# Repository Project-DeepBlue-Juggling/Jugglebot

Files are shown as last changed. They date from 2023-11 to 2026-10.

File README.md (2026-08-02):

# Jugglebot
For all CAD and code related to Project: DeepBlue Juggling

I'll try to release an updated folder here for every episode in which major changes happen.

For further information about the project as a whole, as well as more detail on specific elements of the project, please head to:
pdj.zulipchat.com

## Hardware bench-rig & analysis tools

A single-ODrive bench rig is set up for isolated single-leg characterisation
(brake resistor, separate PSU, isolated CAN bus). The bench scripts and
analysers are documented in [tools/README.md](tools/README.md):

- **Friction characterisation** — Stribeck four-parameter fit pipeline
  (`cogging_bench_test.py` → `friction_study_analyse.py`)
- **Stiction breakaway** — torque-ramp test with position-only escape detector
  (`breakaway_ramp_test.py` → `breakaway_analyse.py`)
- **Friction feedforward demo** — bench-validation of the FF stack
  (`friction_ff_demo.py`)

Canonical reference: [logbook/2026-04-27-friction-feedforward-bench-validation.md](logbook/2026-04-27-friction-feedforward-bench-validation.md).

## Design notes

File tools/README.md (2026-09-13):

# tools/ — Standalone Hardware Test & Debug Utilities

Scripts in this directory bypass ROS2 and talk directly to hardware via python-can. They are designed for bench testing, bring-up, and diagnostics.

## Generators & drift gates (no hardware, no ROS import)

These are the exception to the sentence above: offline generators whose output
is committed and pinned by a test, so the artifact cannot silently rot. Each
regenerates in place; run it and commit the diff when its source of truth moves.

| Script | Generates | Pinned by |
|---|---|---|
| `gen_choreography_map.py` | `ros_ws/docs/choreography.md` — publisher/subscriber/service/action graph of the Python nodes (`--check` exits 1 on drift) | `tests/ros/test_choreography_map.py` |
| `gen_gui_fk_golden.py` | `tests/ros/gui_fk_golden.json` — Python-IK golden poses replayed through `ros_ws/gui/js/stewart-fk.js` under node | `tests/ros/test_gui_fk_golden.py` |

## Preview Convention (`--preview`)

**Scope**: these rules bind the *operator-facing hardware harnesses* — the
scripts in this directory and in `tests/hardware/` that command the robot and
whose `--preview` previews a motion sequence before it is run. They do **not**
bind the offline analysis probes under `tools/probes/`, which run headless on the
Jetson where a matplotlib window is unusable; there `--preview` conventionally
prints the raw per-sample window instead.

**All test harnesses that accept `--preview` must follow these rules:**

1. **Single window** — `--preview` produces exactly one matplotlib figure containing the full test sequence. Never open a separate window per test.

2. **Unified timeline** — All tests in the suite are stitched end-to-end on a shared time axis. The sequence must be C2-continuous throughout: both *during* and *between* individual tests, all commanded values must be smooth (no step discontinuities in position, velocity, or acceleration).

3. **Return-to-home transitions** — Between tests, generate a proper profiled return-to-home move (not a step command). Highlight these transition segments visually (e.g. light blue `axvspan` shading) so they are clearly distinguishable from test segments. After the final test, return to home and then show the stow segment (highlighted in green).

4. **Test boundary markers** — Mark each test's start/end with vertical dashed lines and annotate with the test name/label.

5. **Scrollbar + zoom** — For sequences longer than ~10 seconds, include a horizontal `matplotlib.widgets.Slider` at the bottom for panning, and bind mouse scroll-wheel to zoom in/out centered on the cursor. See `trajectory_viewer.py:_show_continuous_plots()` for the reference implementation.

6. **5-row plot layout** — Use 5 vertically stacked subplots sharing the x-axis:
   - Row 1: Cartesian Pose (mm / rad) — 6 channels, Cartesian colors
   - Row 2: Cartesian Twist (mm/s / rad/s) — 6 channels, Cartesian colors
   - Row 3: Leg Extensions (mm) — 6 channels, leg colors
   - Row 4: Motor Velocity Feedforward (rev/s) — 6 channels, leg colors
   - Row 5: Torque Feedforward (Nm) — 6 channels, leg colors

   Colors and labels are defined in `trajectory_viewer.py` (`LEG_COLORS`, `CARTESIAN_LABELS`, `CARTESIAN_COLORS`). Import them rather than redefining.

7. **`--dry-run --preview`** — Must work without CAN hardware. Run workspace feasibility checks, then show the preview plot using offline simulation only.

**Reference implementations:**
- `smoother_test.py:preview_all_tests()` — streaming/direct-target preview
- `trajectory_viewer.py:_show_continuous_plots()` — trajectory sequence preview

## Common Patterns

### PlatformTestHarness

`free_platform_test.py` defines `PlatformTestHarness`, the shared base for all multi-leg platform tests. Key usage:

```python
harness = PlatformTestHarness(interface='socketcan', channel='can0')
harness.connect()   # Must call explicitly — __init__ does NOT open the bus
with harness:
    harness.home_all()
    # ... run tests ...
```

Also exports: `LEG_AXES`, `encode_set_input_pos`, `encode_set_controller_mode`, `pose_to_raw_positions`, `error_names`.

### WorkspaceLimits

```python
ws = WorkspaceLimits.from_geometry(geom)  # NOT .from_config()
```

### Shutdown: Always Stow

**Every test harness must end with the platform stowed** (all legs at 0 rev, fully compressed). Never idle axes while the platform is raised — an idled motor provides no holding torque and the platform will drop.

The shutdown sequence is: **return to home → stow (0 rev via TRAP_TRAJ) → idle all axes**.

```python
def stow_platform(harness):
    harness.enter_trap_traj_mode_all(vel_limit=1.5, acc_limit=5.0, dec_limit=5.0)
    for axis_id in LEG_AXES:
        harness.states[axis_id].trajectory_done = False
    for axis_id in LEG_AXES:
        harness.send(encode_set_input_pos(axis_id, 0.0, vel_ff=0, torque_ff=0))
    harness.wait_for_all_trajectories_done(timeout_s=15.0)
```

This applies to:
- Normal completion (after all tests pass/fail)
- Error/exception paths
- Ctrl-C handler (best-effort stow, then idle)

Reference implementations: `tests/hardware/free_platform_test.py` and
`tests/hardware/single_leg_test.py`. (The original references — `smoother_test.py:safe_shutdown()`
and `dynamic_target_test.py:safe_idle_all()` — were pre-MPC harnesses removed with
`tests/archived/` in 67889a6, 2026-04-17; recoverable from git history.)

The `--preview` plot must also show the stow segment at the end of the timeline so the operator sees the full motion the robot will execute.

### Safety

All test harnesses share these safety principles:
- Conservative current limit (50% of rated) set before any motion
- Always stow before idling (see above)
- Mandatory feasibility pre-check before hardware execution
- Interactive confirmation before each test stage
- Heartbeat watchdog on all axes

## Test Harnesses

Every row below names a file that exists today. Paths are given because only one
of these harnesses (`tracking_analyzer.py`) still lives under `tools/` — the rest
are under `tests/hardware/`.

| Script | Phase | Description |
|---|---|---|
| `tests/hardware/single_leg_test.py` | 2 | Single-axis bench tests (torque, e-stop, encoder, force) |
| `tests/hardware/supported_platform_test.py` | 3A | Position control bench tests on a single supported leg |
| `tests/hardware/free_platform_test.py` | 3B-C | Platform-level tests; defines `PlatformTestHarness` |
| `tools/tracking_analyzer.py` | 6 | Rosbag analysis for ball tracking data |
| `tests/hardware/cogging_bench_test.py` | bench-rig | Velocity-mode bench runner with `--sweep`. Produces friction-vs-velocity sweeps for Stribeck fitting. |
| `tests/hardware/breakaway_ramp_test.py` | bench-rig | Torque-mode ramp from rest. Position-only escape detector measures stiction per starting electrical angle. |
| `tests/hardware/torque_step_test.py` | bench-rig | Bidirectional torque-step terminal-velocity test. Reveals controller-fight overhead in velocity-mode measurements. |
| `tests/hardware/friction_ff_demo.py` | bench-rig | Friction-FF effectiveness demo: pos_step / vel_step / sweep modes with Stribeck FF, stiction-boost, and vel_ff toggles. |

**Pre-MPC harnesses (removed 2026-04-17).** Nine harnesses this table used to
list — `trajectory_test.py`, `inertia_test.py`, `hardening_test.py`,
`dynamic_target_test.py`, `juggling_test.py`, `smoother_test.py`,
`trajectory_viewer.py`, `catch_sim_test.py`, `throw_catch_test.py` — were deleted
with `tests/archived/` in commit 67889a6. They exercised the pre-MPC quintic
path-following controller (`control_loop.py`, archived with them) and were
already excluded from pytest. Their test *scenarios* remain valid references for
future MPC hardware tests; recover any of them with
`git show 67889a6^:tests/archived/<name>`.

### Friction characterisation & FF demo (single-leg bench rig)

Four scripts under `tests/hardware/` form a complete friction-characterisation and feedforward-validation pipeline for a single ODrive leg on an isolated CAN bus. Used during the 2026-04-24 to 2026-04-27 bench-validation phase of the motion-onset dead-time investigation.

**Canonical reference:** [logbook/2026-04-27-friction-feedforward-bench-validation.md](../logbook/2026-04-27-friction-feedforward-bench-validation.md) — the bench-validation arc, withdrawn hypotheses, and final fit parameters.

**Pipeline:**

```bash
# 1. Fit Stribeck friction model from a velocity sweep
python tests/hardware/cogging_bench_test.py --sweep 0.075,0.10,0.20,0.30,0.50,1.0,2.0,5.0
python tools/friction_study_analyse.py --glob 'temp/logs/cogging_<ts>*.csv'

# 2. Measure stiction breakaway per rotor angle
python tests/hardware/breakaway_ramp_test.py --direction both --trials 8
python tools/breakaway_analyse.py temp/logs/breakaway_<ts>.csv

# 3. (optional) Confirm against terminal-velocity in TORQUE mode
python tests/hardware/torque_step_test.py

# 4. Validate friction FF + stiction-boost + vel_ff in POSITION mode
python tests/hardware/friction_ff_demo.py
```

All four scripts share safety conventions: 3 rev stroke cap, brake-resistor-aware acceleration cap (250 rev/s²), heartbeat watchdog, IDLE-on-exit. See each script's `--dry-run` output for current parameter limits.

### Friction-FF analysis tools (`tools/*_analyse.py`)

| Script | Inputs | Outputs |
|---|---|---|
| `cogging_map_analyse.py` | one cogging CSV | iq-vs-electrical-angle map, harmonic R² (n=1..12), position-drift slope |
| `friction_study_analyse.py` | multiple cogging CSVs (a sweep) | Stribeck four-parameter fit (τ_c, τ_s, ω_s, b), tracking-quality plots, fwd-vs-rev electrical-map Pearson R |
| `breakaway_analyse.py` | breakaway summary CSV | per-direction breakaway iq stats, angular-dependence harmonic fits, sanity check that breakaway moved more than half a cogging period |

All three accept `--json <path>` to emit a machine-readable result; plots go to `temp/reports/`.

### Tilt calibration grid (contract C-LEVEL-2)

Pose-dependent gravity-level calibration: `level` measures the platform's tilt
against gravity at **one** pose and applies that offset at **every** pose, so
pose-dependent kinematic error is invisible to it by construction. These two
tools measure it over an (x, y) grid and ship it as an interpolatable residual
map.

| Script | Role |
|---|---|
| `tests/hardware/tilt_cal_grid.py` | **Operator-run** capture. Drives the grid via `trajectory/go_to_pose` (never arms, never changes modes, never commands the hand), reads the inclinometer N times per node, writes `config/tilt_calibration.yaml`, reloads it in the running node, verifies the applied version, then re-measures off-node check poses. Runs under **system python3.8 with ROS 2 sourced** — not the venv. |
| `tools/tilt_cal_analyse.py` | Offline. Heat maps + quiver of the residual field, per-node sd table, outlier flagging, and a `--diff` mode for map-invariance (rung C2). Accepts `--json`; reports go to `temp/reports/tilt_cal_<ts>/`. |

**Runbook — read it before running either:** `tests/hardware/session_tilt_calibration.md`
(rungs C0–C3 with numeric PASS/ABORT). Contract: `ros_ws/docs/levelling_frame.md`
§ C-LEVEL-2. Plan: `plans/archived/tilt-calibration-grid.md`.

`tilt_cal_grid.py` takes `--dry-run` (prints the node order and ETA, makes zero
ROS calls) rather than `--preview`: it commands no continuous motion sequence to
plot — it is a series of discrete rest-to-rest moves — so the five-row preview
layout above does not apply. `tilt_cal_analyse.py` is offline analysis and takes
no preview at all, matching `cogging_map_analyse.py`.

⚠ **Several defaults are PROVISIONAL until rung C0 measures them on hardware**
(`--dwell-s`, `--n-reads`, `--read-gap-s`, `--threshold-deg`, the home-node
gate bounds, and the analyser's curvature-flag constants). The SCL3300's noise
floor is unmeasured in this repo; C0 exists to pin it before any test asserts a
threshold.

### catch_sim_test.py

Offline catch simulation that exercises the full pure-Python pipeline: `BallTracker` (Kalman filter + marker matching) → `CatchCoordinator` (catch pose + hand commands) → `TrajectoryManager` (async feasibility + trajectory execution). No ROS2 or hardware required.

**3D visualization** (`--viz`): animated Stewart platform with ball trajectory, KF estimate, landing prediction, hand state indicator, landing error chart, and event timeline. Supports pause/step (Space, arrow keys).

### throw_catch_test.py

Throw-catch cycle: platform throws a ball to itself ((-100,0,170) → (100,0,170) mm), repositions during flight, and catches. Validates the full pipeline including hand throw/catch trajectory timing, platform tilt for throw, and hand catch offset. Reuses the `catch_sim_test.py` animated 3D visualizer.

```bash
python tools/throw_catch_test.py           # text-only results
python tools/throw_catch_test.py --viz     # animated 3D playback
python tools/throw_catch_test.py --viz --apex 500   # lower throw (500mm apex)
```

### catch_sim_test.py

Offline catch simulation that exercises the full pure-Python pipeline: `BallTracker` (Kalman filter + marker matching) → `CatchCoordinator` (catch pose + hand commands) → `TrajectoryManager` (async feasibility + trajectory execution). No ROS2 or hardware required.

**3D visualization** (`--viz`): animated Stewart platform with ball trajectory, KF estimate, landing prediction, hand state, leg extensions, and event timeline.

```bash
python tools/catch_sim_test.py --viz                           # Default throw
python tools/catch_sim_test.py --viz --landing 50 -30          # Specific landing XY
python tools/catch_sim_test.py --viz --landing 0 0 --launch 300 -300 900  # Custom launch
python tools/catch_sim_test.py --landing 0 0 --tof 1.0        # Longer flight
python tools/catch_sim_test.py --viz --noise 10                # High mocap noise
python tools/catch_sim_test.py --sweep                         # Noise sweep (text table)

# Playback controls (--viz):
#   SPACE       play/pause       . / ,     step +1/-1
#   ] / [       step +10/-10     0 / 9     first/last frame
```

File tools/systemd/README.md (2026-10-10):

# User systemd units

Reference copies of the `systemctl --user` units that arm
[`tools/nightly_suite.sh`](../nightly_suite.sh). The **live** copies live at
`~/.config/systemd/user/` — systemd does not read this directory. These are here
so a reimaged or replacement Jetson can be re-armed from the repo, and so a
reviewer can see what is scheduled without shelling into the box.

`nightly` is only an honest test tier while something runs it. If the timer is
lost, every `@pytest.mark.nightly` test silently stops running while
`./run_tests.sh` keeps printing PASS. Treat re-arming as part of any Jetson
rebuild.

## Install / re-arm

```bash
install -Dm644 tools/systemd/jugglebot-nightly.service \
  ~/.config/systemd/user/jugglebot-nightly.service
install -Dm644 tools/systemd/jugglebot-nightly.timer \
  ~/.config/systemd/user/jugglebot-nightly.timer
systemctl --user daemon-reload
systemctl --user enable --now jugglebot-nightly.timer

# Linger must be on, or the user manager (and the timer) stops at logout:
loginctl show-user "$USER" -p Linger      # want Linger=yes
sudo loginctl enable-linger "$USER"       # if it is not
```

## Verify

```bash
systemctl --user list-timers jugglebot-nightly.timer --all
systemctl --user status jugglebot-nightly.service     # last run's exit
tools/nightly_ticker.sh check --who "<session>"        # CLAIMED|LOWERED|STALE|UNRAISED|NEVER — the once-per-day claim; read status only on CLAIMED
cat temp/reports/nightly/status                       # GREEN|RED|DEFERRED <counts> <date>
```

## Keeping these in sync

The install is a **copy**, not a symlink, so the two can drift. `systemctl
--user enable` records the unit by name and a symlinked unit file confuses its
alias handling, which is why this is not symlinked. If you edit a unit, edit it
here, re-run the install block above, and say so in the logbook entry.

Armed 2026-08-01 (`logbook/2026-08-01-nightly-tier-and-mpc-dormancy.md`).

## System unit: `jugglebot-gui.service` (GUI server + replay API)

Unlike the nightly units above, this is a **system** unit
(`/etc/systemd/system/`, `User=jetson`), serving the GUI on :8081 and the
`/api/replay/` rosbag-replay routes. The server itself is stdlib-only and runs
under `/usr/bin/python3`; it lists recordings and serves the `.mcap` bytes over
HTTP Range (the browser decodes them itself). Only the overview worker it spawns
on demand (niced, one at a time) needs the venv, via `--worker-python`; its
results land in `temp/replay_overview/` (gitignored, tens of kB each, `--overview-dir`).
The rosbags root is passed on the `ExecStart` line.

**Migration (Phase 4):** the converter cache is gone. After installing the new
unit, remove the old cache: `rm -rf temp/replay_cache/` (up to 10 GB).

```bash
sudo cp tools/systemd/jugglebot-gui.service /etc/systemd/system/
sudo systemctl daemon-reload
sudo systemctl restart jugglebot-gui
systemctl status jugglebot-gui
```

**Do not restart while someone is using the GUI**: the restart drops every open
page's connection and kills a running overview pass (it is re-run on the next request). Edit the unit here, then re-run the block above;
the install is a copy, so the two can drift.

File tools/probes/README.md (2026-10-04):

# tools/probes/ — Reusable Empirical-Probe Harnesses

Probes fall into two families:

1. **Offline drivers** — scripts that drive the MPC / controller stack in
   a production-faithful way from recorded telemetry, to reproduce
   hardware failures, characterise edge cases, or empirically confirm
   threshold values before they get encoded in tests.
2. **Live observers** — scripts that record system state alongside a live
   session (real robot, real ROS2 stack, real MPC) so a later analysis
   pass can attribute failures to hardware bottlenecks (CPU saturation,
   thermal / DVFS throttling, memory bandwidth, etc).

**These probes are committed to the repo** — distinct from one-off
exploratory probes which still go to `/tmp/probe_*.py`. The split is
codified in `CLAUDE.md`'s "Empirical probe before writing tests" rule.

## Why committed probes exist

Logbook entries and test docstrings reference probes by path. When the
probe lives in `/tmp/`, any reboot wipes the reference. Reusable
harnesses — anything a future investigation is likely to re-run or
adapt — go here so the references stay live.

## Probe conventions

- **Outputs**: probes write CSV / JSON / report files to `temp/probes/`
  (auto-gitignored under the umbrella `temp/` rule). Never write
  run outputs inside `tools/`. Prefer a **timestamped** filename so
  successive runs in one session accumulate rather than clobber each
  other (`fk_convergence_bag_check.py` and `cone_bag_decode.py` both do
  this).
- **Committed reference fixtures** live in `tools/probes/data/`. A probe
  whose gate replays a recording under gitignored `temp/` needs a
  committed cut of it, or the gate is unrunnable on a fresh clone — and
  that cut needs a committed *recipe* (an explicit-output regeneration
  flag), since a fixture nobody can re-baseline is only half a live
  reference. This is the one exception to "no outputs inside `tools/`":
  reference data, not run output, and written only by an explicit flag.
  **Exception, by fixture SHAPE, not by probe**: a fixture that is a
  handful of *measured constants* rather than a data cut is written as an
  importable `.py` under `tests/`, next to the test that reads it —
  `possession_verdict_bag_check.py --emit-fixtures` →
  `tests/ros/possession_fixtures.py`,
  `possession_replay.py --emit-fixture` →
  `tests/ros/toss_verdict_replay_fixtures.py` (the borderline case, and
  it earns the shape: 31 rows of schedule constants plus 157 run-length
  segments, which a reviewer can read, rather than the 21,435 raw
  samples they were cut from). The reason is
  reviewability: a census of a dozen numbers is something a human checks
  and argues with in a diff, and burying it in JSON under `tools/` makes
  a re-baseline look like a blob swap. Data *cuts* (thousands of samples)
  stay in `tools/probes/data/` — e.g.
  `hand_sensor_replay_fixture.json`. Either way the recipe rule is
  unchanged and absolute.
- **Header docstring**: each probe's top-of-file docstring states what
  the probe replays / characterises, the logbook entry that motivated
  it, and the test (if any) whose empirical recipe it underpins.
- **README row**: every committed probe gets a row in § "Available
  probes" below, in the **same commit** that adds the probe. A probe
  nobody can find from this file is a probe nobody re-runs — Phase 0 of
  the 2026-07 refactor programme had to backfill a missing
  `canbridge_reboot_latch_probe.py` row for exactly that reason.
- **Self-contained**: probes set up `sys.path` themselves so they run
  with `python tools/probes/<name>.py ...` from the repo root without
  needing the project venv to be on `PYTHONPATH`.
- **Offline drivers — no hardware**: read recorded telemetry CSVs from
  `temp/logs/` and drive the MPC stack via Python imports, not ROS2 /
  ZeroMQ. Reproducibility against the pinned dependency stack is the
  whole point.
- **Live observers — hardware-allowed, side-effect-free**: may launch
  alongside a real session, but must only *observe* (read `/proc`,
  spawn `tegrastats` / `pidstat`, attach `py-spy`). Never command the
  motors, never send ROS2 messages — that's `tests/hardware/` territory.
  (Carve-out: the GUI verification harness `gui_synthetic_stack.py` and the
  rosbridge CPU probe `rosbridge_cpu_probe.py` publish *synthetic telemetry*
  ROS2 messages, each guarded in code three ways — it refuses to start
  unless the ROS graph is EMPTY, it re-checks the graph at ~1 Hz while
  running and on any foreign node immediately disables all publishers and
  tears itself down (`gui_synthetic_stack.py`) or tears every child down
  outright (`rosbridge_cpu_probe.py`, a batch tool with no state to degrade),
  and it never publishes on a topic any node treats as a
  command. `rosbridge_cpu_probe.py` adds a fourth rail beyond
  `gui_synthetic_stack.py`'s: it runs entirely on a private, non-default
  `ROS_DOMAIN_ID` (87) that it sets for every child it spawns and refuses to
  run on domain 0, so even a race between its graph-empty check and a
  publisher coming up cannot reach a real robot node living on the robot's
  own domain.)

## Available probes

### Offline drivers

| Probe | Purpose | Motivating logbook entry |
|---|---|---|
| `caught_window_bag_probe.py` | The one number behind `skills.executor.CAUGHT_WINDOW_S`: per caught throw, the delay from the ball tracker's own DESCENDING crossing of the 830 mm catch plane (`/balls`, linearly interpolated between the samples either side, candidate tracks filtered to those that actually rose above 880 mm) to the first debounced SEATED sample on `/hand_telemetry` (`ball_held_valid and ball_held`). Both series on their own header stamps, never bag receive time. Reads MCAP through `mcap_ros2` — which decodes from the schema the bag itself carries, so `jugglebot_interfaces` need not be built or sourced, and `rosbag2_py` (absent from the project venv on Foxy) is not needed either. **Report the bags SEPARATELY**: the delay is not one-signed (09-16 ran +43..+282 ms, 09-15 ran −39..−48 ms on all 22 throws), and a statistic pooled across that sign flip is not a physical quantity. ~5 min per 140 MB bag even with the topic filter, so run it in the background. | [2026-09-16-outcome-window-and-computed-catch-deferral](../../logbook/2026-09-16-outcome-window-and-computed-catch-deferral.md) |
| `outcome_landing_replay.py` | **Which landing estimate would the row have recorded?** Replays a bag's `/balls` stream against the memory rows a sitting actually wrote and prints, per throw, the commanded flight, the y as written, the y the CURRENT rule picks (through `executor._consider_landing` itself, not a copy) and whether the physical band admits it. Everything here is in FLIGHT TIME, the quantity that sitting's rows recorded; since 2026-09-18 the learner's outcome is an APEX, so the probe derives its flight band as `sqrt(memory.APEX_RATIO_BAND)` and cannot replay the apex or converged-fit tests (those bags carried neither the landing velocity nor `landing_from_fit`). Built for the 2026-09-16 contamination (rows of 2.2317 / 2.2310 / 1.1554 s for an 0.8569 s command): over both that day's sittings, **43 written rows → 21 refused, 22 admitted at y/u 0.974–1.528** (as written: 0.979–2.985), with the OLD rule reproduced within 12 ms on all 43 — which is what licenses the comparison. Also the instrument that KILLED a candidate rule: "prefer the estimate with the smallest lead to its own crossing" turned three genuine rows into 0.02–0.05 s flights, because the tracker's first post-release estimates predict an immediate crossing. Offline, read-only, needs the project venv + `mcap_ros2` (no ROS2). `--bag` (repeatable), `--learn`, `--date`. | `logbook/2026-09-16-outcome-landing-frozen-at-the-crossing.md` |
| `cone_bag_decode.py` | Decodes the catching cone's `/cone/*` topics straight out of rosbags into a one-command per-session evidence table: `/cone/heartbeat` count, `connected` (n_true/n_total), `time_synced` (n_true/n_total + **was it synced from the FIRST heartbeat?** — the column that settles "did the cone ever sync this session"), `last_catch_seq` range → `taps` (wrap-aware, **reboot-aware** genuine tap count), `/cone/catch_event` count, `/cone/timing_result` count. The `taps` vs `catch_ev` cross-check is load-bearing: `taps` is what the CONE believed happened, `catch_ev` is what the ROS graph actually PUBLISHED — a divergence (` !` in the table) means catch frames were lost in between. Handles both cone firmware eras: the modern `have_any_catch`-gated seq (pre-first-catch `last_catch_seq` is a placeholder) and the legacy May firmware that never set the flag at all (falls back to a plain wrap-aware delta) — `taps == catch_ev` on 17/17 sessions of 2026-07-12 **and** 3/3 legacy `cone_test_*` bags with catches. **Read that 17/17 with its condition attached**: it validates the cone→ROS transport only *because no catch followed either in-session cone reboot* (`18-34-09`, `18-44-56`, both `*`-marked) — a cone MCU reboot resets `last_catch_seq` to 0, and the probe now detects the reset (`have_any_catch` clearing, or an implausible >64-tap single-heartbeat step), restarts the accumulator and marks the row, instead of bridging straight across it and inventing ~250 phantom taps. A genuine count of **zero** is reported as `0`, never as "topic absent" (`-`) — the distinction is drawn from the bag's channel list, because collapsing a real 0 into "absent" silently suppressed the exact frames-lost case the probe exists to detect (cone counted N taps, ROS graph published ZERO `catch_event`s — i.e. the `catch_correlation_node` orphan). `-` now means the bag has no channel for that topic at all. Offline and read-only (opens `.mcap` files only; no node, no socket, no hardware) and needs NO ROS2 — `mcap_ros2` decodes the schemas embedded in the bag, so it runs on a non-ROS2 clone. `--bag` / `--all` (`--match <date>` to narrow; a full ~230-bag sweep takes ~6 min — cost is chunk decompression, not decode) / `--json` (copy to `temp/probes/`). Degrades gracefully on unreadable bags (per-bag `ERROR:` row, sweep continues) and on a missing `--root` (clean error, not a traceback). | `logbook/2026-07-12-gui-cone-catch-correlation-regression.md` (the `timing` column is ground truth for that fix: `/cone/timing_result` is **0** in every session before the rebuild, non-zero after) + `logbook/2026-07-12-cone-sync-udp-link-contention.md` (this probe REFUTED the "cone only syncs right after a colcon build" model — `sync@1st` is `Y` for every session from 15:57 on, straight across the 19:17 rebuild boundary and for three further launches 45 min–3 h later. It then refuted that entry's OWN first attribution of the two dead morning sessions to a co-binding bench harness: the `connected` fractions and the `*` reboot markers show the same dropout-then-reboot signature in sessions with **no bench process running at all**, and a partial-connectivity session (`20-03-36`, 155/593) is a shape an all-or-nothing UDP bind race cannot produce — pointing at cone-side power/wiring intermittency instead) |
| `bench_leg_plant_id.py` | Leg-plant system-ID from recorded `bench_leg_sysid.py --mode strokes` CSVs — offline, no hardware, no new bench runs. Two fits per gain point: (a) the **plant**, by regressing the rigid-body torque balance `2πJ·a = Kt·iq − τ_c·sgn(v) − b·v` on the (a, v, iq) triples → `J_eff`, `τ_c`, `b`; and (b) the **tracking-error budget**, decomposing `err = cmd_u0 − encoder` into `τ_d·v + k_a·a + k_f·sgn(v) + c` → how much of the error is even *attackable by feedback* (the delay term is not: it is gain-independent, and much of it is the metric's own sample-and-hold, since `cmd_u0` is the knot at the START of the segment the firmware is interpolating THROUGH). Prints the cascade table `ω_v = vel_gain/(2πJ)` vs `ω_p = pos_gain` — the ratio that actually decides whether a gain point rings, and which the gain ladder never measured. **Result: `J_eff` = 0.7–1.2 × J_rotor across five independent fits (two highest-R² both at 0.97×), refuting the unsourced "J_eff ~10× rotor" guess the tuning methodology had carried since 2026-04-27 by an order of magnitude; `τ_c` = 0.88–1.22 A, bracketing the 2026-04-27 friction bench's 1.094 A — reproduced from unrelated data.** Caveats in the header docstring — `a` is a numerical derivative so this is ±~20%, good enough to settle a 10× hypothesis and size a feedforward, not a precision inertia measurement; and the bench leg is UNLOADED (no gravity, coupling or hand reaction), so these are a floor, not the loaded-robot budget. `python tools/probes/bench_leg_plant_id.py --all`. | `logbook/2026-07-13-leg-plant-id-and-the-units-bug.md` (the session that ended the leg gain hunt: the "accuracy knee" that motivated the retune was a rev→mm units bug, and the plant this probe identifies shows the cascade was already healthy at production gains) |
| `toss_trace_synth.py` | Synthetic-trace generator + end-to-end verification matrix for the Phase-3 toss-choreography checker (`tests/hardware/toss_trace_recorder.py check`): generates the 2 happy-path traces (waived dry ending `Toss MISSED`; un-waived `REJECTED_NO_BALL`) plus the faithful `ABORTED_NO_RELEASE` variant (dispatch eaten, THROWING reached, no stroke — must banner, SKIP exactly DT-9/DT-12 with DT-5 still evaluated via the THROWING proxy, and exit 0) plus BOTH continuous happy-path traces — `cont_happy` (3-cycle `TossContinuous` session, every cycle CAUGHT: the `ACTION_STAY` teardown) and `cont_dry` (every cycle MISSED: the `SAFE_ABORT` teardown, which is the shape the runbook's MANDATORY CONT-STEP-1 pre-flight actually produces and whose ~10 rev retract lands inside every dwell window CS-3 measures) — plus ONE violation trace per invariant (25 cases, DT-1..14 + RJ-1..4 + CS-1..6 with CS-3 carrying two, one per half — each flips exactly the ordering/property its invariant checks), then `--verify` runs the REAL checker on all 30 and asserts the matrix: happy/variant ⇒ exit 0, every non-SKIP invariant PASS; violation ⇒ exit 1, exactly the targeted invariant FAILs, zero collateral. Includes the empirically-confirmed 2026-07-25 audit inversion (`viol_dt5`: hand cmd-echo changed BEFORE the announcement) which the pre-fix DT-5 silently PASSed — the fixed checker's pre-announcement negative scan hard-FAILs it. Pure stdlib, no hardware, no ROS. `python tools/probes/toss_trace_synth.py --all --verify`, exit 0 = matrix clean. Traces to `temp/probes/toss_trace_synth/`. Re-run after ANY checker change. **2026-07-29**: `viol_dt7` had gone VACUOUS (DT-7 stopped being an "exactly one dynamic_target" count when it was reworked to bound the pre-position STREAM to 30 mm of the nominated point) and the matrix reported MISMATCH at HEAD; the case now injects a target that WANDERS to (95, 0, 170), which is what DT-7 actually guards. **2026-07-29 (Phase F finalize)**: added `cont_dry` and `viol_cs3_hand`. The CS-1..CS-6 matrix had only ever been shown clean on an all-CAUGHT session, while the runbook makes an all-MISSED dry trace the mandatory gate BEFORE any ball flies — an instrument validated on one side only. Adding `cont_dry` immediately surfaced two real CS-3 defects (a hand bound inherited from DT-5's idle window, and a baseline that landed on the retract ramp), both fixed in the checker. | `logbook/2026-07-25-toss-phase3-prep-trace-harness.md` (Phase 3 prep of `plans/archived/single-ball-toss.md`); CS-1..CS-6 added for Phase F (`toss_continuous`) |
| `ilc_speed_band.py` | **DELETED R1 (2026-09-11).** Swept the critical-point-ILC `event_vel_trim` channel against `throw_envelope.evaluate`'s now-deleted `ARM_WINDOW` bound (a reactive-catch-stroke model retired with the mastery latch); not imported by any live test, only cited in prose by `tests/hardware/ilc_fit_lib.py`, `tests/motion/test_ilc_fit.py`, `tests/motion/test_throw_envelope.py` and `tests/ros/test_toss_ilc_node.py` (the critical-point ILC stack itself is superseded, see `plans/archived/critical-point-ilc.md`). | `logbook/2026-08-21-ilc-primary-foldin.md` |
| `cadence_rung_check.py` | **DELETED R1 (2026-09-11).** Drove both FSMs against the legacy per-cycle cadence ladder (`tests/hardware/session_cadence_ladder.md`) and the reactive stroke engine's dispatch budget; the device it verified is retired with the mastery latch. Pinned by `tests/motion/test_cadence_rung_check.py` (also deleted). Its only remaining importer, `tools/probes/toss_loop_census.py`, was itself **DELETED R4 (2026-09-24, `census_fsm_deletion.md` Cluster A)** with `toss_sequencer.py` (the probe read `toss_sequencer.LoopPeriodCensus`'s JSONL output) — both halves of this cross-unit follow-up are now gone. | ILC-primary fold-in Phase K/L — `logbook/2026-08-21-ilc-primary-foldin.md`; cadence-floor + B1 follow-up — `logbook/2026-08-23-cadence-floor-and-inertia.md` |
| `uplot_nan_gap_probe.js` | Node-driven regression probe for the GUI telemetry charts' gap semantics: extracts the SHIPPED `nanGaps` hook verbatim from `ros_ws/gui/js/telemetry-charts.js` and drives the REAL vendored `ros_ws/gui/lib/uPlot.iife.min.js` linear path builder with it, asserting NaN runs render as pen-up gaps (never false bridging lines) — 21 assertions incl. edge runs, all-NaN, single-point NaN, null+NaN merge, dashed-stroke invariance. Pins uPlot-1.6.31-specific behaviour (gap scanner honours strict `null` only; the chart store's Float64Array columns can only carry NaN). Re-run on any uPlot upgrade or `nanGaps`/series-wiring change. `node tools/probes/uplot_nan_gap_probe.js`, exit 0 = pass. | `logbook/2026-07-11-gui-leg-setpoint-echo-poscmd.md` (review HIGH #1: false bridging ramp across stale windows) |
| `fk_convergence_bag_check.py` | Offline FK-convergence verdict for a recorded session: replays every `/robot_state` encoder vector and every `/leg_setpoint_echo` commanded vector from a rosbag through the PRODUCTION `leg_lengths_to_pose` and reports, per topic, how many reconstructions raise under (a) the production default criterion — **the verdict, must be 0** — and (b) the historical absolute-only criterion (`rtol=0, stall_ceiling_mm=0`) — **must be > 0 or the verdict is vacuous**, because it counts how many vectors in that session actually reached the round-off floor; a session whose poses all happen to land under 1e-10 mm reads identically to a genuinely fixed one, so the probe reports that case as a loud `VACUOUS` banner rather than a PASS. Also reports the residual band of the historical failures, the worst residual accepted at the default, and the worst Newton iteration count (50 before the fix, 5 after). Baseline on bag `2026-07-25_15-17-48`: `/robot_state` **514/28953 (1.775 %)** and `/leg_setpoint_echo` **37/10453 (0.354 %)** fail under the historical criterion, 0 under the default; worst accepted residual 9.07e-10 mm; ~92 s per bag (cost is chunk decompression). Strictly offline and read-only — opens `.mcap` files only, no node, no socket, no hardware — and needs NO ROS2 (`mcap_ros2` decodes the schemas embedded in the bag). `--bag` / `--all` (`--match <date>`) / `--json` (→ `temp/probes/`). Exit 0 = PASS, 1 = a reconstruction still fails or a bag was unreadable. | `plans/archived/fk-convergence-tolerance.md` Phases 0–1 — the bare absolute `tol=1e-10` mm was below the reachable round-off floor at part of the workspace, and `trajectory_node`'s seed path turned that into a hard "not streaming until a valid state" refusal (26 consecutive ERRORs in 286 ms on 2026-07-24 09:08:55). The failure is spatially **clustered**, not rare: ±1 encoder dead-band around the burst pose fails **96.8 %** of the time, vs 0 % at `z=50`/`z=110` flat — which is why it bursts. Consuming test: `tests/motion/test_fk_convergence.py` (both its hardware fixtures were extracted with this probe's decode path) |
| `levelling_tilt_bag_check.py` | Offline levelling-frame (C-LEVEL-1) verdict for a recorded session: FK-reconstructs the **commanded** platform pose from every `/leg_setpoint_echo` vector and reports the commanded-tilt **plateau structure** — every run where `rx` sits still, with start time, duration and value in degrees — then, given the session's published offset (`--offset TILT_X TILT_Y`, radians, from the orchestrator's `Gravity offset published:` line), scores three numbers. **`park_rx`/`park_ry` (the longest plateau — where the platform RESTS) is the verdict**, and it is the whole fix in one number: pre-migration the platform parked at plan-frame `rx = 0` while corrected surfaces asked for `-0.7788 deg`, so PASS is `park` within `--tol` (default 0.05 deg) of `(-tilt_x, -tilt_y)`. `settle_rx` is the plateau **furthest from the park in the correction's own direction** (the catch settle — not the last, because post-migration the session ends parked at the corrected neutral; and sign-aware rather than a hard-coded `min()`, which returns the PARK for a positive-rx correction). `peak_above_park` is REPORTED and **never gated**: post-fix it equals the platform's physical peak tilt against gravity and equals `(16/81)*rate*|tdir_x|*lead` = **0.789132 deg per second of catch lead** exactly, so any fixed threshold on it is really a threshold on the lead — the retired `+3.099 deg` ABORT would have fired on a healthy system at any lead >= 3.93 s. The probe prints `implied lead` instead, which on a healthy post-fix session recovers the toss's actual catch lead (the pre-fix bag reads 2.94 s against a true 3.70 s). **Read the header docstring's CAVEAT before scoring**: commanded `rx` is NOT flat across a catch goal and the plan's original "flat to +-0.05 deg across the whole goal" criterion is unreachable — `build_catch` ramps a tilt-through-seat residual along `catch_pose[3:5]`, which with a correction loaded is the correction itself, settling the platform `0.5*0.07*0.15 = 0.005250 rad = 0.3008 deg` OFF gravity-level at ball contact. **Validated on BOTH shapes, which is the acceptance criterion for a verdict instrument.** FLAG side, the real pre-fix bag `2026-07-25_15-17-48` (toss window `--t0 165 --t1 200`, 4.5 s): `park +0.0000 deg` (the defect), `peak +2.3224` above a `0.0000` park, `settle -1.0775` against the closed form `-1.078408` — **err 0.0009 deg**, which is what confirms the through-seat attribution against hardware; 0 FK failures; VERDICT FAIL, correctly, because that bag predates the migration. ACCEPT side, `--self-check` (no bag needed, ~3 s): three sessions synthesised through the PRODUCTION `planner.build_catch` — post-fix must PASS, pre-fix must FAIL, and post-fix contaminated by a 30 s pre-`go_home` ACTIVATE hold must FAIL **with the ambiguity note**, because that hold is commanded at plan-frame `rx ~ 0` and is *correctly* uncorrected (a seed is never corrected), so on a healthy session it can win the longest-plateau vote and read exactly like the pre-fix frame. Hence `--t0` after the first `go_home` is mandatory in CHECK LVL-3. Without the ACCEPT half the instrument would have scored a working fix as FAILED at the bench. Strictly offline and read-only (opens `.mcap` only; no node, no socket, no hardware) and needs NO ROS2. `--bag` / `--root` / `--offset` / `--tol` / `--plateau-tol` / `--plateau-min-s` / `--t0` / `--t1` / `--json` (timestamped, into `temp/probes/`) / `--self-check`. Exit 0 = PASS or STRUCTURE-ONLY (no `--offset`), 1 = park outside tol or unreadable bag. | `plans/parked/levelling-frame-contract.md` Phases 1-2 (and Phase 4, which this is the verdict instrument for) — `trajectory_node` applied the correction on some pose-ingest paths and not others, so the toss's positioning `go_to_pose` parked at plan-frame `rx = 0` while the pre-tilt `catch/dynamic_target` asked for `-0.7788 deg` and `build_catch` planned a min-jerk reach between the two frames, arriving 0.7 s before release. Contract: `ros_ws/docs/levelling_frame.md`. Consuming tests: `tests/ros/test_levelling_frame.py`, `tests/motion/test_levelling.py`, `tests/motion/test_levelling_probe.py` (the two-sided self-check, guarded in CI) |
| `catch_reach_replay.py` | Offline reproduction of a recorded **catch reach** through the production `planner.build_catch`, plus the *install census* that says how many plans spanned it. Three outputs. (1) **Install census** — `move_seq`, `plan_kind`, `last_rejection`, accepted `target_feedback` and `catch/dynamic_target` inside the plan's own window, plus plan-end drift (`t + plan_time_remaining_s`). Five clauses, none sufficient alone. **The load-bearing ones are single-valued `move_seq`, single-valued `plan_kind` (a `HoldPlan` reads `hold`, which is how the emitter backstop / escalation hold / freeze-in-place become visible — they bump nothing else) and zero accepted `target_feedback`.** Plan-end drift is NOT decisive and is not described as such: `_plan_and_install_catch` derives its lead from a fixed `arrival_perf`, so a re-plan to the SAME arrival leaves the plan end untouched — the reference bag's own post-release burst runs `move_seq` 53→64 with 14 accepted feedbacks and drifts **1.02 ms**, LESS than the 1.9 ms across the genuinely zero-install window. There is likewise no status-vs-diagnostics rate advantage: one 5 Hz timer publishes both (1453 messages each over 290.6 s). A rejection only counts if it was RAISED inside the window — `last_rejection` is a lifetime latch that never clears, so gating on "non-empty" would fail every reach after one unrelated session rejection. (2) **The `peak_leg_*` verdict** — it rebuilds the plan and compares the `FeasibilityReport` peaks against what the bag published (`14.2 / 142.4 / 3950`, identical at the published precision — rebuilt `14.2401 / 142.4440 / 3949.7`; the decisive half is the `0.0 / 0.0 / 0` the preceding `go_to_pose` install wrote, which proves the field is WRITTEN). The field is **per-plan, not stale**; it repeats across *these* catch installs because a catch plan's predicted peaks are the fixed-shape 0.15 s through-seat decay's peaks **whenever the reach is small enough for that decay to dominate**. Not a general property: a reload-sized reach runs `82.5→30.1→24.7→15.2→14.0 mm/s` over leads 0.8→8.0 s, and the same bag's two reload catch installs published `23.6` / `23.8` against the toss catches' `14.2` — so predicted peaks MOVING between two catch installs is normal, not evidence of a non-catch plan in between. (3) **The replay** — `build_catch` seeded only from recorded inputs (FK seed pose, `levelling.correct_pose` of the wire target, arrival = `landing − _PRETILT_EARLY_S`), sampled and differenced against FK of `/leg_setpoint_echo`; ONE scalar is fitted (the emit→echo pipeline lag) and the zero-lag residual is reported alongside. All **seven** catch reaches in `2026-07-25_15-17-48` reproduce: 5 self-toss pre-tilts (rx rms 0.005–0.006°, max ≤ 0.039°, lag +10.5 ms) and both reload pre-tilts (rx rms 0.003°, max 0.009°, lag +9.5 ms). The headline closed form is the **amplification** `(16/81)·rate·T / \|tilt\|` = peak *unrequested* excursion ÷ requested displacement — direction-only, so it blows up as the requested tilt → 0: **3.76 for the 0.78° toss pre-tilt, 0.17 for the 11.08° reload pre-tilt**, one code path, 22× apart. That is the whole answer to "why is an 11° reach clean and a 0.78° one not". Verdict tolerance is `max(--tol-deg, --tol-frac × commanded span)` — a purely absolute bound scores the clean 11° reload as NOT-REPRODUCED on a 0.5 % error. **Validated on BOTH shapes, which is the acceptance criterion for a verdict instrument**: the FLAG case (`--toss 2`, the excursion) and the ACCEPT case (`--thrower ball_butler --toss 2`, the clean 11° reload) both read REPRODUCED / exit 0, and `--self-check` case 7 compares all **nine** mirrored rows against their production sources so a change to any of them fails the instrument loudly instead of silently re-scoring old physics. Two of those rows are the 2026-07-26 seat-rate split: `PLANNER_DEFAULT_THROUGH_SEAT_RATE_RADPS` (0.0 — the LIVE default, so raising it off zero breaks the self-check) and `THROUGH_SEAT_RATE_RADPS` (0.07 — a **capture record** of what the reference bag ran at, pinned to itself so nobody "helpfully" syncs it to the new default and makes every pre-2026-07-26 reach score NOT-REPRODUCED). **(4) The C-CATCH-1 counterfactual (added 2026-07-26).** Every scored row also rebuilds the SAME recorded inputs through the post-fix path (`build_fixed`: seat aimed at the gravity-referenced wire tilt, arrival rate left to the planner so `ros_ws/docs/catch_arrival_contract.md`'s bound applies) and prints the delta — unrequested (wrong-side) excursion, settle, segment count, predicted peaks, and whether the `2.5·|d|/T` bound binds. On the reference session the self-toss reach goes `2.3239° → 0.0000°` unrequested excursion with the settle landing dead on the target. **Updated 2026-07-26:** `_CATCH_TILT_THROUGH_RATE_RADPS` now ships at `0.0` (the builder manufactures no motion; an explicit `tilt_through_rate_radps` is still honoured verbatim), so `build_fixed` — which deliberately tracks the shipping planner — now rebuilds the reload reach with **no seat at all**: `3 → 2` segments, arrival rate `0.070000 → 0.000000 rad/s`, settle `+1.8235/−10.9330° → +1.7741/−10.6363°` (exactly the target), predicted `23.8/139.7/3873 → 29.0/37.9/170` mm/s·s²·s³. The earlier "keeps its seat, aim rotated `4.0997°`, settle moved `0.0215°`" reading was the counterfactual at the `0.07` rate and is retained in `ros_ws/docs/catch_arrival_contract.md` § Consequences, because separating the **frame** fix's effect from the **zero-rate** decision's effect is what a bench disagreement needs. REPORTED, never gated — the verdict is about reproducing what the robot DID run, which is why `build_replay` deliberately keeps rebuilding the PRE-fix plan (it passes the arrival rate explicitly, which under C-CATCH-1 means caller-requested and therefore unbounded); a probe that could not express the physics a capture contains could not reproduce it. Self-check cases 9 and 10 make that two-sided and pin the bound factor to `min_s ψ/|φ| = 5/2`. `/gravity_offset` is resolved at the INSTALL, not at end-of-bag, so a mid-session re-`level` cannot score earlier reaches with a later correction. Strictly offline and read-only (opens `.mcap` only; no node, no socket, no hardware) and needs NO ROS2. `--bag` / `--root` / `--toss` / `--thrower` / `--list` / `--offset` (defaults to the bag's `/gravity_offset`) / `--tol-deg` / `--tol-frac` / `--pre` / `--post` / `--json` / `--csv` (both timestamped, into `temp/probes/`) / `--self-check`. Exit 0 = reproduced and the census is self-consistent, 1 = not reproduced, contradictory census, or unreadable bag — **a non-reproduction is a publishable result, not a probe bug**. | `plans/archived/catch-reach-degenerate-overshoot.md` Phase 0 — a `−0.77878°` catch target produced a `+2.32°` commanded excursion in the OPPOSITE direction, settled at `−1.0784°` (1.385× the target), with a leg acc/jerk spike at release − 0.6 s. All three are one plan doing what `build_catch` specifies: the quintic acquiring its specified terminal arrival rate (`φ = −4s³+7s⁴−3s⁵`, extremum `−16/81` at `s = 2/3`), the through-seat overshoot `1 + 0.5·rate·decay/\|tilt\|`, and the 0.15 s through-seat decay segment (10× the reach's acceleration, 113× its jerk). Consuming test: `tests/motion/test_catch_reach_replay_probe.py` (the model-vs-production-planner self-check, guarded in CI). Sibling: `levelling_tilt_bag_check.py`, whose FK reconstruction this reuses |
| `possession_verdict_bag_check.py` | Replays every `/balls` message in a rosbag through the **production** possession source (`jugglebot.ball_possession.TrackerArrivalSource`, constructed exactly as `reload_coordinator_node` constructs it) and prints, per destination-tagged track that reached `CAUGHT`, the estimate, the ARRIVAL error, the REPORT-only plane drop and the verdict the TRACKER SOURCE alone returns. ⚠ **Since owner decision D1 (2026-08-26) that is NOT the coordinator's verdict** — possession is the cup's alone (C-POSSESS-1.D) and the tracker supplies report-only `arrival_err_mm`; for the machine's answer use `possession_replay.py`. This probe scores the tracker's CONTRIBUTION and owns the corpus its split-track behaviour is characterised from. Turns a capture into the two numbers the runbook's `POSS-1` row needs — how many CAUGHT verdicts the gate minted vs how many catches the operator counted by eye — without re-running the sitting. Also **owns the committed test fixtures**: `--emit-fixtures` regenerates `tests/ros/possession_fixtures.py` (all 35 tagged-track CAUGHT estimates of 2026-07-27, 17 self-toss + 18 reload) so the contract's tests are scored on measured ground truth rather than synthetic points. `--self-check` is the two-sided instrument acceptance and needs **no bag**: ACCEPT side (all 17 real catches confirmed), REFUSE side (0/18 corrupt tracks confirmed), the >10x population separation, the bound sitting strictly between them, the retention pin, the 2026-07-23 second-session negative, and **two drift guards mirroring the node's own tolerance and catch point** — 8/8, exit 0 (run 2026-07-28). The reference point defaults to the ACTIVE catch point because a bag does not carry the live goal; `--ref X Y Z` scores a displaced-catch session. Strictly offline and read-only (opens `.mcap` only), `mcap_ros2` imported lazily so the scoring half runs without the bag reader. Outputs a timestamped CSV to `temp/probes/`. | `the anomaly-fixes orchestration prompt (completed, deleted 2026-08-15)` § Follow-on programme, item **B** (cross-referenced from `plans/archived/catch-reach-degenerate-overshoot.md`, whose `CCATCH-2t` row this un-blocks) — the CAUGHT gate was **structurally always False**: it ANDed `\|z − catch_z\| <= 150 mm` onto a quantity that is a dead-reckoned free-fall extrapolation (the tracker declares CAUGHT *because the marker vanished*), so all 17 self-toss catches of 2026-07-27 read `z` error **305–1007 mm** against `xy` error **0.30–3.88 mm** and every one scored MISSED. Contract: `ros_ws/docs/ball_possession_contract.md` (C-POSSESS-1). Consuming test: `tests/ros/test_ball_possession.py`; consuming runbook row: `tests/hardware/session_anomaly_fixes.md` § SECTION POSS |
| `possession_replay.py` | **What would the machine have called each cycle, under the SENSOR-ONLY verdict?** — the acceptance instrument behind owner decision **D1** (2026-08-26). For every self-toss cycle in a bag that reached a release it reconstructs exactly what the live node would have asked the cup: the cycle's SCHEDULED landing (`t_release + flight_time`, the FSM's own `landing_perf`), the cadence clamps `reload_coordinator_node._set_toss_next_cycle_perf` latches (`next_release = landing + dwell`, `next_landing = next_release + flight`, `prev_landing`, including the `intends_another_cycle` rule that decides whether they are latched at all), the real `/hand_telemetry` stream fed sample-by-sample into the shipped `HandBallSensorSource`, and the verdict read at the FSM's OWN deadline `landing + CATCH_CONFIRM_WINDOW_S` through `merge_possession`. **The verdict surface is production; the ask-cadence is modelled** — the label and the edges come from the installed modules, while *when* to ask is restated from the node’s arithmetic (audit N14, 2026-08-26); the reader was `toss_record_miner.read_bag`, deleted 2026-09-13 (R3-f1) — `main()`'s `--bag` path is unreachable until this probe is rebuilt without it; the tested surface below is unaffected. On the reference sitting `2026-08-26_14-25-16` it reproduces the cup census **exactly**: **23 CAUGHT / 4 MISSED** over the 27 cup-adjudicated cycles, every row matching the offline `ball_possession.label_from_sensor` label, against the shipped tracker-primary code's **11 / 16** — 15 false MISSED (twelve of them tracks the tracker never confirmed at ALL, three with a tracker CAUGHT 0.615–0.830 s past the landing) and 3 false CAUGHT over an empty cup, one of which drove a phantom reload. `--emit-fixture` owns `tests/ros/toss_verdict_replay_fixtures.py` in the `possession_fixtures.py` shape (an importable `.py` of measured constants carrying its own regeneration recipe), run-length compressed **21,753 samples → 162 segments**, and the compression is **VERDICT-EQUIVALENT on `(label, blind, catch_dt_s)` at emit time against the source bag** — checked, not claimed: the probe replays both the raw and the expanded stream and refuses to write a fixture whose triples differ. It is NOT lossless (the encoding re-lays sample instants on a nominal `step_s` grid), and the gate is sound for THIS source only, because `HandBallSensorSource` reacts to exactly three things and all three are segment boundaries. **The verdict SURFACE here is production; the ASK-CADENCE is modelled** — the probe reconstructs *when* the node would have asked from the node's own arithmetic, and does not cross the seam that actually failed (`_build_toss_observations` → the FSM). `tests/ros/test_possession_replay.py` carries one node-level test that does. Strictly offline and read-only (opens `.mcap` only). | `logbook/2026-08-26-possession-verdicts-become-sensor-only.md`. Contract: `ros_ws/docs/ball_possession_contract.md` (C-POSSESS-1 § 3.2, clause **D**). Consuming test: `tests/ros/test_possession_replay.py`. Siblings: `hand_sensor_verdict_replay.py` (the same stream with full hindsight, both windows closed — this one answers at the FSM's deadline) and `possession_verdict_bag_check.py` (the tracker's report-only half) |
| `hand_sensor_verdict_replay.py` | Replays a session's **hand ball sensor** through the production possession verdict: reads `/hand_telemetry` + `/throw_announcements` out of a rosbag, feeds every sample into the shipped `jugglebot.ball_possession.HandBallSensorSource` (same `JB_BD_*` windows the node constructs it with) and prints, per announced throw, the sensor's label resolved with **full hindsight** (both windows closed) — `CAUGHT` / `BOUNCE` (arrived then left) / `MISSED` (window closed with no empty→held edge) / `UNKNOWN` (the sensor could not look — which since D1, 2026-08-26, REFUSES rather than falling back to the tracker, and reaches the FSMs as `MISSED_SENSOR_BLIND`). That is the verdict the coordinator would have minted for every label **except `BOUNCE`**: the coordinator answers on the first confirmed tick, where retention is still UNKNOWN and is contract-forbidden from vetoing, so a `BOUNCE` row is a live `CAUGHT` plus the C-POSSESS-1 § 7 reporting residual — which is exactly why it is worth counting offline, being the one count no live log carries — with the **catch-event time** (`arrival edge − predicted landing`), plus the whole-bag sensor ledger (sample count, `ball_held_valid` fraction, transition counts, held-segment durations, sub-second seat-then-leave events). This is the instrument that SIZED the shipped windows: over the three 2026-08-10 retest bags (`16-04-26` / `16-13-48` / `16-30-44`; **203,922 samples, 100 % `ball_held_valid`**, 81 announcements) it labels **35 CAUGHT / 46 MISSED / 0 BOUNCE / 0 UNKNOWN**, with the catch band **+137…+798 ms** (median +399) against a nearest non-catch edge at **+3194 ms** — a ~4x separation, which is what `arrival_lead_s 0.20` / `arrival_window_s 1.50` sit inside. Its transition counts reconcile **exactly** with an independent hand count on all three bags (5/6, 24/23, 38/39 rises/falls). `--merge-tracker {refuse,confirm}` prints the MERGED counterfactual, making the restored-verdict count visible (under the measured pessimistic tracker the pre-2026-08-10 machine mints **zero** catches on these bags; the sensor restores all 35). `--self-check` is the two-sided acceptance and needs **no bag** — 10/10, exit 0 (run 2026-08-10): both ends of the measured catch band ACCEPT, the +3194 ms re-seat REFUSES, the 0.999 s seat-then-leave reads BOUNCE while a hold past the window reads CAUGHT, a **1.55 s hold at the shipped 1.50 s window reads CAUGHT** (the absolute widen guard — the relative case above it follows the constant and can only catch a narrowing), a blind window reads UNKNOWN, a ball that never left raises no edge, and — since D1, 2026-08-26 — the ABSENCE of a tracker fallback is checked in both directions (a confirming tracker cannot rescue a blind cup; a refusing one cannot veto a confirming cup). `--emit-fixture --t0 --t1` owns the committed cut `tools/probes/data/hand_sensor_replay_fixture.json` (16,444 samples of `2026-08-10_16-30-44` over `[140, 305) s`, carrying the band-maximum +798 ms catch, five further catches, two misses and all three seat-then-leave events) and stores its own regeneration recipe inside the file. Strictly offline and read-only (opens `.mcap` only; no node, no socket, no hardware), needs **no ROS 2**, `mcap_ros2` imported lazily so the scoring half runs without a bag. `--json` writes a timestamped report to `temp/probes/`. | `logbook/2026-08-10-sensor-truth-possession.md` — the phase that made the hand sensor the PRIMARY possession source and flipped `toss_require_ball_evidence` to `true`. Contract: `ros_ws/docs/ball_possession_contract.md` (C-POSSESS-1 §§ 3.2, 3.3). Consuming test: `tests/ros/test_hand_sensor_replay.py`. Sibling: `possession_verdict_bag_check.py`, which does the same job for the TRACKER half of the merged verdict |
| `toss_loop_census.py` | **DELETED R4 (2026-09-24, `census_fsm_deletion.md` Cluster A).** Read `toss_sequencer.LoopPeriodCensus`'s JSONL output to answer whether `NODE_LOOP_PERIOD_S = 0.040` was still a bound; `toss_sequencer.py` (the FSM ring) is deleted in the same commit, so the instrument it read no longer exists. Was probe P1 of Phase B0, `plans/archived/toss-pipelined-preamble.md` § 5.1 — see that plan and `logbook/2026-08-26-toss-loop-period-census.md` / `logbook/2026-08-26-phase-b0-measure-first.md` for the historical readings (0.040 s was NOT a bound: 53/73 chained cycles exceeded it, 2026-08-27). | `logbook/2026-08-26-toss-loop-period-census.md`; `logbook/2026-08-26-phase-b0-measure-first.md`; `plans/archived/toss-pipelined-preamble.md` § 5.1, probe P1 |
| `ball_arrival_offset.py` | **Where each thrown ball actually ARRIVED.** For every `/throw_announcements` entry in a rosbag it reads the raw mocap marker stream (`/mocap_data`, unlabelled markers only — the ball carries no rigid body) and reports the ball's `(x, y)` at a horizontal plane (`--plane`, default **1000 mm**) as a least-squares fit of `x(z)`/`y(z)` over the DESCENDING samples in `[plane, plane+band]`, plus `n` and the fitted `z` span. Exists because the 2026-07-27 sitting could not decide its own headline question — three bounce-outs off a stationary 10.8° rim against a measured 26–39 mm BB warm-up drift in arrival `x` — and the A/B that settles it compares outcomes **at matched arrival offsets**, a number the session did not produce (the sitting's own gap list: *"Nothing asks for the ball's measured arrival point... it appears in no log line"*). **Three design points are load-bearing, not stylistic**: the fit is cut at the first sub-plane sample so a bounce-out's post-contact excursion (up to ~70 mm, and in a different direction on different balls) cannot bias a track by an amount that *correlates with the outcome being scored*; it is a fit rather than a nearest-sample read because mocap drops the ball for tens of ms exactly when a track is worst (ball 11 was lost at `z = 1111` and never re-acquired), and `n < 5` is flagged `SPARSE` rather than silently trusted; and a lateral gate removes the room's fixed reflector at `(−537.1, 412.9, 1163.7)`, which sits squarely in the arrival band. `--group NAME=lo-hi` (repeatable) + `--discard N` produce the per-block mean/sd and the matched-arrival check the SEAT-EXP decision rule reads — expressed against the **standard error of the difference of means**, not a flat threshold, because at the measured 9–11 mm sd and `n = 12`/arm a fixed 5 mm gate fires on identically-aimed blocks 17–28 % of the time. It also prints a `PLATEAU (last 8 scored)` mean, which is the statistic `SEAT-EXP-2.2` gates on: the all-scored mean still carries the warm-up excursion and is biased ~10 mm toward passing (`−28.8` vs `−38.9` on the reference capture). **Note `--group` selects on the ANNOUNCEMENT index**, which counts throws that produced no ball (4 of 18 on the reference capture), so the runbook requires one bag per arm rather than counted ranges. **Validated two-sided against the sitting (2026-07-28)**: at `--plane 1050` it reproduces all three published bounce-out entry points — ball 6 `(−6.6, 16.2)` vs `(−7.2, 16.1)`, ball 9 `(−18.5, 3.9)` vs `(−18.8, 3.6)`, ball 11 `(−21.0, 7.6)` vs `(−21.5, 7.4)`, worst error **0.6 mm** — and the population mean `−35.11 mm` vs the published `−34.9`. **Scope that 0.6 mm to what it measures** (bounce-out entry points, at `--plane 1050`) — it is agreement with one published quantity, not this estimator's accuracy: against the sitting's published `x@z1000` series the probe differs by up to **12.7 mm** (attempt 2, `−21.6` published vs `−8.9` here) and by 3.0–3.9 mm on three others, because two defensible estimators on sparse tracks disagree by far more than 0.6 mm. That disagreement is between-estimators and systematic, so it cancels within a sitting (this probe is deterministic and scores both arms) — which is exactly why the decision rule is within-sitting and `SEAT-EXP-6` is expressed against its own standard error rather than a flat millimetre gate. **One number deliberately does NOT reproduce and is recorded rather than buried**: the sitting's *"attempt 3 dropped at −10.7, attempt 4 caught at −14.5, 3.8 mm apart"* reads **−11.507 / −11.525 here, 0.02 mm apart** — the old pair came from an ad-hoc fit whose window is unrecorded and attempt 3 is the capture's sparsest track (3 samples, all above `z = 1100`). The qualitative reading is unchanged and sharper, but it is why **no absolute number from the hand analysis is a gate** and the SEAT-EXP rule is within-sitting with both arms scored by this probe. The floor census (new resting clusters after each attempt) is **REPORT-only** and its measured failure mode is documented in the header: it over-counts a rolling ball and under-counts two balls resting within `--floor-radius` (attempt 3's rested 111 mm from attempt 2's, so it merges and reads 0). Deliberately NOT tuned to make that capture come out right. `--self-check` is the no-bag acceptance: **8 cases**, two-sided (recovers a known crossing to 0.084 mm; proves the post-contact cut holds — as a real MUTATION check, grafting the bounce-out back INSIDE the fit band and requiring the naive fit that kept those samples to move (481 mm here), after a 2026-07-28 review found the original graft sat at `z = 700`, i.e. *below* the plane where the band filter drops it either way, so a probe with the cut deleted scored `8/8 PASS, exit 0`; re-verified both ways — mutant now `FAIL (1 case)` exit 1, unmutated `PASS` exit 0; extrapolates a sparse high-only track; REFUSES a track that never enters the band; sample-sd `n−1`; a one-sample block reports NO sd rather than 0.0, which would make the instrument's own data loss decisive; and **two cases on the sitting's real numbers** — the burn-in trend gate must REFUSE the measured warm-up (`−7.13 mm/throw`) and ACCEPT the measured plateau (`−1.75`), while the criterion the sitting first proposed (*successive change < 10 mm*) is pinned as one that FIRES ON A GOOD PLATEAU (largest successive change there is 15.6 mm), so it cannot be re-adopted from the prose). Strictly offline and read-only, `mcap_ros2` imported lazily, timestamped CSV to `temp/probes/`. | `plans/archived/catch-reach-degenerate-overshoot.md` follow-on phase C — the seat rate became the YAML key `trajectory_op.catch_seat_rate_radps` so the A/B is a config toggle; this probe is what makes "matched arrival offsets" a measurement. Evidence base: `logbook/2026-07-28-anomaly-fixes-validation-sitting.md`. Consuming test: `tests/motion/test_ball_arrival_offset_probe.py`; consuming runbook rows: `tests/hardware/session_anomaly_fixes.md` SECTION SEAT-EXP (`SEAT-EXP-4`, `SEAT-EXP-6`, `SEAT-EXP-7.1`) |
| `hand_decel_authority.py` | Characterises the hand's POST-RELEASE deceleration from a `toss_trace_*.jsonl` and answers the one question that decides the shape of a fix: is the plant **AUTHORITY-limited** (achieved decel saturates ⇒ steepening the commanded ramp changes nothing) or **TRACKING-limited** (achieved follows commanded with a shortfall ⇒ more commanded braking torque buys margin directly)? Per self-toss it emits the commanded decel and `t_dec` re-derived from the SHIPPED firmware header (`Teensy_code_platform/hardware_config.h`, namespace `TeensyTraj` — parsed, not copied), the measured `peak`, `over_x3`, the implied tracking fraction `eta = d_dec/(d_dec + over_x3)`, max \|iq\| over the decel ramp (anchored on the COMMANDED profile, with the count of genuinely fresh `iq` samples in that window) and over the arrest, the residual velocity feedforward standing after the stroke, and the settled `pos_meas - pos_cmd`; per tier it adds the decel-side reflected-inertia LOWER BOUND `(tau_FF + tau_grav)/(2*pi*a_achieved)` and the authority table it implies at `hand_curr_limit_a`. On the 2026-07-27 sitting it measured `eta` = **0.982 / 0.985 / 0.921 / 0.799** at 2.74 / 3.44 / 3.97 / 4.86 m/s — i.e. the achieved deceleration keeps GROWING (911 → 2330 rev/s²) with no ceiling in sight, and the whole-session max \|iq\| is **25.67 A against a 50 A limit** — so the plant is tracking-limited, not current-saturated. But the same table shows the commanded decel at the shipped `FLIGHT_TIME_MAX_S = 1.10 s` is already **83-86 % of the axis's torque-limited ceiling**, which is why steepening was rejected and the feedforward corrected instead. **The caveat is load-bearing and is printed by the tool**: `hand_telemetry` is a ~100 Hz snapshot of a 500 Hz stream and `iq_meas` has a median repeat-run of **4 samples** (mean 7.8, max 918) ⇒ effective refresh ~13-25 Hz, so every current is a LOWER bound and **the gated bench rows must rest on the KINEMATIC columns, not the current ones** — which is why the per-tier inertia bound it prints uses no `iq` measurement at all (binding value **1.0126e-5 kg·m²**; the regression identification 1.050e-5 lives in the contract). It also refuted a hypothesis in passing: the settled `pos_meas - pos_cmd` offset (per tier: **+0.067** at 2.74 m/s, **+0.043…+0.066** at 3.44, **+0.019…+0.041** at 3.97, **−0.004…+0.007** at 4.86 — it SHRINKS with speed) is NOT the residual velocity feedforward, whose median through the same windows is 0.00-0.02 rev/s. **Two defects of one class were found and fixed 2026-08-23, and both were upstream of every number above.** (1) **The window.** `peak` was the max `pos_meas` over the ~400 ms after the commanded stroke end, and `over_x3` / `eta` / the inertia bound all derived from it — but C-HAND-1's gated catch arm dispatches its prelude 37–183 ms into that window and climbs back past `x3`, overshooting by a measured 0.046–0.222 rev, so on any throw whose own coast tops out lower the reported peak is **the arm's move ~200 ms after the throw**. Measured contamination: **10 of the 17 tosses of the 2026-07-27 sitting the C-HAND-2 numbers come from** (both low tiers on every toss — reported `over_x3` +0.074/+0.063 rev against coasts that actually finished −0.051/−0.092 rev, i.e. BELOW `x3`), and **15 of 15** on the first ladder flown unclamped. The identification columns are now bounded at the first post-stroke command (`cst_pk` / `cst_min` / `over_x3` / `under` / `eta` / the bound); **`peak` deliberately keeps the wide window** because the end-stop question wants the largest excursion of ANY cause, and a `*` marks the tosses where the two differ. (2) **The torque.** The per-tier bound multiplied `tor_legacy` — the pre-C-HAND-2 feedforward — long after Platform FW 2 put `throwDecelToTorque` aboard, understating the shipped braking torque by **1.289×** and the bound with it; it now reads the latched wire torque off the capture and PRINTS which generation it found. A third column, `under`, carries the over-brake side, which no maximum over any window can express. **The bound is also no longer asserted unconditionally**: it is a LOWER bound only while the coast finishes above `x3`; a coast that ends below it never caught `pos_cmd`, so `τ_loop` pushed up and the same expression is an UPPER bound — flagged per tier, because the two cases cannot be pooled. Strictly offline and read-only. `--self-check` (two-sided synthetic gate: a PRE-fix capture must score FLAG and a POST-fix one ACCEPT, through the same `analyse()` the bench uses — bench row INST-6; both synthetics now carry the arm prelude, without which the window bug passes its own gate) / `--trace` (one or more) / **`--bag`** (rosbag directories — what the § CHECK HAND-7 recording command actually produces; before this the named authority could not read the capture the ladder makes) / `--robot` / `--curr-limit-a` / `--json` (→ timestamped file under `temp/probes/`). Now exercised by `tests/motion/test_hand_decel_authority_probe.py` (7 cases, mutation-verified) — until then nothing in the suite executed this file at all. | `logbook/2026-07-28-anomaly-fixes-validation-sitting.md` (§ Discussion → *the hand's end-stop margin above 0.78 m*, and the 2026-07-28 amendment: the hand made **light physical contact with its end stop**). Underpins contract **C-HAND-2** (`ros_ws/docs/hand_decel_feedforward.md`) and its tests `tests/sim/test_hand_throw_decel_ff.py` + `tests/firmware/test_hand_throw_decel_xref.py`. Re-run by `tests/hardware/session_anomaly_fixes.md` § CHECK HAND-7 to score the post-flash capture against these pre-fix numbers. |
| `hand_contact_softness.py` | **Is the catch IMPACT measurable on the hand drive channels?** — the Phase-0b probe of `plans/archived/critical-point-ilc.md`. For every catch in a bag it extracts `/hand_telemetry` `vel_meas` / `iq_meas` around the arrival edge and answers, in the order the plan fixes: (1) the **cadence census** — *distinct-value transitions per second*, not samples, because `iq_meas` reaches the bag through the on-change (\|Δiq_setpoint\| > 0.5 A) / 1 Hz-forced DIAGNOSTIC path and is republished at 100 Hz from a cache (`Teensy_code_canbridge/telemetry.cpp:21,24,61` + `teensy_bridge_node.py:2271`), so the publish rate is not the refresh rate; (2) the **transient census** against a stated noise floor AND — the part that actually decides it — two **matched controls**: a same-duration window 0.5–0.8 s earlier in the same cycle (paired, sign-tested) and the same window on a MISSED toss at matched phase (same choreography, no ball); (3) the pre-registered outcome (i)/(ii)/(iii) from an explicit rule, plus a fourth **UNREGISTERED** cell the plan does not enumerate, reported rather than rounded into the nearest box. **Result: the naive comparison is a trap and the probe exists to say so.** Contact-window peak \|Δvel\| on `2026-08-10_16-30-44` is 1.715 rev/s against a *static* floor p99 of 0.195 — an apparent 8.8× (measured 2026-08-12) — but the hand is not still at contact, `vel_meas` tracks `vel_ff_cmd` to ~1 % through the catch stroke (−12.136 vs −12.320, −28.186 vs −27.720, −42.978 vs −43.120 rev/s on three consecutive samples), and at **matched phase CAUGHT vs MISSED separate by 1.03× on \|Δvel\| and 1.45× on the iq impulse** (both under the 1.5× bar; measured 2026-08-12 with the iq impulse referenced to a DISJOINT quiet-held baseline — referencing it to the control window's own median, as the first cut did, scores the control at its own L1 minimum and manufactured a 3.55× within-cycle "separation" out of null data) — i.e. not at all. Two floors are always reported (static / moving) for exactly this reason. Reads the bag through `toss_record_miner.read_bag` + `mine_bag` (the labelling authority; that reader was deleted 2026-09-13, R3-f1 — `--bag`/`analyse_bag` are unreachable until this probe is rebuilt without it, `--self-check` is unaffected) and adds one light second pass for the drive fields, which are not part of `SensorSample`. `--bag` (repeatable) / `--all --match` / `--json` (→ `temp/probes/`) / `--self-check` (**28 synthetic cases, exit 0, run 2026-08-12**, every DETECT twinned with a REFUSE; its command profile is periodic at *exactly* the contact→control offset so the zero-impact case cannot separate on the command alone — the first draft did, and reported "resolvable" on a series containing nothing). Sequential bag processing (8 GB box). Consuming test: none (`tests/ros/test_ilc_measurement_probes.py`, deleted 2026-09-13 R3-f1, was its last one — its target probes were not themselves deleted). | `plans/archived/critical-point-ilc.md` § Phase 0b + § Design constraint 4 (contact softness) + risk 2; the SNR→0 framing (owner, 2026-08-11) is what the matched controls operationalise |
| `hand_sensor_settle.py` | **The messy-catch score** — the Phase-0d probe of `plans/archived/critical-point-ilc.md` (owner metric, 2026-08-12: the hand sensor is highly reliable, so a reading that bounces between BALL and EMPTY after arrival is a messy catch). Order fixed by the plan: (1) the **distinct-sample cadence census** — `ball_held_stamp` advances, not `/hand_telemetry` messages, since the flip count is bounded by the poll and not the 100 Hz republish — which **re-verified the toss-build 2a findings exactly on the reference bag** (poll p5 32 / p50 71 / p95 111 ms vs a configured 20; debounce lag 0/0/0 ms on the catch edge, 232/241/295 ms on the departure edge) **and then refuted them as a standing plant property**: across the eleven bags (ten 2026-08-12 sittings plus the 2026-08-10 reference) the poll p50 runs 20, 20, 40, 50, 50, 54, 71, 71, 71, 72, 76 ms — two sessions at the *configured* rate — and the departure-edge debounce lag tracks it (110 ms at a 20 ms poll, 200 ms at 54 ms, 241 ms at 71 ms), so `sensor_poll_dt_ms_median` must be read per record and never assumed; (2) the **flip census swept over W** (0.5–3.0 s) with recall and false-positive columns, so W is derived from the plateau rather than picked — the reference bag selects **0.75 s**, the plateau's low end and the smallest window recalling all three known quick-drops; (3) the score, its distribution, threshold and error rates. **The score is the RAW `ball_held_raw` flip count, and the argument is from the data**: the *debounced* count within W ≥ the quick-drop bound is the ground-truth definition restated (it separates perfectly and demonstrates nothing), while the raw count is not implied by the label — it finds catches the possession label calls clean that flipped the raw bit twice and settled, which is exactly the rattle the owner's framing describes. Pooled over 11 bags / 58 catches at W = 0.75 s, threshold ≥ 1: **recall 3/3, false-clean 0 %, false-messy 3/55 = 5.5 %** → pre-registered outcome (i). Imports the miner's reader/ledger/labels, `toss_record.edges` (so a "flip" cannot drift from what the robot means by one) and — since 2026-08-24 — `toss_record.poll_dt_steps_ms`, so the cadence census's STEP RULE is the same one the mined `sensor_poll_dt_ms_median` field carries and this file defines only the reduction; anchors on sensor edges rather than announcements because 8 of the 10 2026-08-12 bags carry **no `/throw_announcements` at all**. `--bag` / `--all --match` / `--window-s` / `--json` / `--self-check` (**38 cases, exit 0, run 2026-08-24**, every MESSY twinned with a CLEAN, driven at the MEASURED 71 ms poll not the configured 20; the four newest pin the transient-low-stamp re-anchor and the wall-anchor epoch change, which the private step rule reported as a 571 ms and a 1.79e12 ms "poll"). Consuming test: none (`tests/ros/test_ilc_measurement_probes.py`, deleted 2026-09-13 R3-f1, was its last one — its target probes were not themselves deleted). | `plans/archived/critical-point-ilc.md` § Phase 0d + § Command vector (the hand-sensor-settle channel); cadence facts re-verified against `logbook/2026-08-10-toss-selftuning-build.md` §§ 2a-2, 2a-3 |
| `hand_poll_cadence_census.py` | **How often did the bridge actually POLL the hand ball sensor?** — the per-bag and per-corpus census of distinct `ball_held_stamp` advances, reported as p5 / p50 / p95 / max against the configured `JB_BD_CHECK_INTERVAL_MS` and beside the bridge uptime each bag opened at. `/hand_telemetry` republishes its cached bit at 100 Hz while the sensor is polled far slower, so the census counts **stamp advances, not messages** — counting messages would report the publish rate for every plant. **Nothing is re-implemented**: the step rule is `jugglebot.ball_possession.poll_dt_steps_ms` (the same definition the mined `sensor_poll_dt_ms_median` field on every `toss_record/1` row carries, pinned by `tests/ros/test_ball_possession.py` § 2b) and the reader was `toss_record_miner.read_bag(..., sensor_only=True)` — deleted 2026-09-13 (R3-f1), so `--bag`/`--all`/`main()` are unreachable until this probe is rebuilt without it; `--self-check` supplied the `/hand_telemetry` clock rule and the `/link_status` uptime covariate stayed the reduction under test; the only thing this file defines is the **reduction**, which is what `--self-check` covers. Committed so a logbook entry's tables are **re-derivable rather than trusted** — the entry it backs cites this probe for the reference bag, the reboot A/B pair, the post-FW-14 sweep and the uptime correlation. Read an elevated row as *investigate*, never as a mechanism: the bridge's poll loop is strictly one-in-flight on a 10 ms task grid, so `C = 10·max(2, ceil(RTT/10)+1)` and **anything** that slows the round trip raises C. Out of scope by design: `/ring_diag` ring occupancy — see `logbook/2026-08-14-s3-conviction-ring-leak-measured.md` for that. `--bag <name-or-path>` (repeatable) / `--all --match '<glob>'` / `--root` / `--json` / `--self-check` (**8 groups, exit 0, run 2026-08-24**). | `logbook/2026-08-24-hand-sensor-poll-cadence.md` |
| `displaced_reach_frontier.py` | **How far a displaced self-toss can actually reach, per the production planner.** Sweeps the Tier-8b deferred A→B catch reach across 8 directions × 7 flight times × 8 radii by building the REAL chain (`toss_release.compute_release_state_tilted` for the swing-compensated pre-tilt seed at A and the aim, the receive tilt from the ARRIVAL velocity, the swing-compensated catch centroid at B, then `planner.build_catch` with the flight as the lead) and reporting accepted-direction counts against the closed-form quintic bound the FSM gated on (retired with it). ⚠ **2026-08-29..2026-09-24 that chain was PRODUCTION CODE, not the probe's own** (`motion/trajectory/catch_reach.py`, when `_build_toss_cycle` grew a pre-throw gate on it — `reach_verdict` delegated there, pinned by `tests/motion/test_catch_reach.py::test_the_frontier_probe_delegates_to_this_module`). **PORTED BACK at R4 (2026-09-24, `census_fsm_deletion.md` Cluster A)**: `catch_reach.py`'s only other caller, the FSM's `reload_coordinator_node.py`, was deleted in the same commit, so the module lost its production caller and the body moved back into this probe (its only remaining caller) rather than the probe losing its last one — see `reach_verdict`'s docstring. No production code calls this any more; it is purely a measurement again, same as before 2026-08-29. Also answers three sibling questions in one run: which off-centre throw sites can reach 150 mm inside a ±150 mm survey box (`--off-centre-radius` / `--box`), whether the DEGENERATE `B == A` case plans and is BITWISE the Tier-8a vertical toss (the operator's "8b subsumes 8a" expectation, never flown on hardware), and where `MAX_TILT_DEG` binds. Pure in-process planning — no MuJoCo, no bag, seconds not minutes; `--json` writes a timestamped result to `temp/probes/`. | `plans/archived/single-ball-toss.md` Phase E and `the anomaly-fixes orchestration prompt (completed, deleted 2026-08-15)` § Follow-on programme item **E**. The old 70 mm displacement cap was justified as *the 80 mm reach envelope ∩ the Rung-2a clean box*; contract **C-REACH-1** (`ros_ws/docs/catch_reach_envelope.md`) removed the envelope half, so the cap needed its own evidence. Measured 2026-07-29: the real all-8-directions frontier is **125 mm at T = 0.55 s, 175 mm at 0.60, ~225 mm from 0.70 up**, so the closed-form bound is CONSERVATIVE below T ≈ 0.75 s and OPTIMISTIC above it. That asymmetry was the argument for keeping a flat `toss_max_displacement_mm` cap beside the bound; the owner deleted the cap on **2026-08-29** (it was a chosen number, not a derived one, and ramping difficulty through a YAML edit + regenerate is the wrong ergonomics at the machine), so this measurement is now the record of the residual that decision ACCEPTS. That residual shrank the same day: the audit fix that added the build-time reach gate covers the OPTIMISTIC half above T ≈ 0.75 s pre-throw (it asks `build_catch` exactly the question `trajectory_node` would have answered at `t_release`, and mints `REJECTED_POSITION(<planner code>: …)`), so what is actually accepted is the ergonomics plus the CONSERVATIVE half below T ≈ 0.75 s, where the closed-form bound refuses feasible throws one gate earlier. Underpinned `reach_displacement_limit_mm`'s docstring and the residual paragraph in `toss_sequencer` (both deleted with the FSM at R4, 2026-09-24) and `tests/ros/test_toss_sequencer.py::test_displacement_rejected` / `::test_reach_displacement_limit_closed_form` (same); `ThrowTiltInfeasible`'s "contract, not a live constraint" claim survives (`toss_release.py`, kept); `tests/hardware/session_anomaly_fixes.md` § SECTION DISP. |
| `link_status_health_scan.py` | **"Did behaviour X change across a can-bridge flash?"** — the generic form. Reads every `/link_status` message out of one or more rosbag sessions and reports, per session, the span, the can-bridge `uptime_ms` span, and the **value duty cycle of each watched KeyValue row** (`bus1_health[OK=480(58%),WARN=354(42%)]`), plus which *marker* rows were present at all — a KeyValue that exists only in a newer firmware / ROS build is itself a deployment fingerprint (`hand_ball_sensor` is present in the 2026-07-29 22:37 bag and in no earlier one, which is what proves FW4 ran). `/link_status` is the bridge's whole observable state surface and almost every row on it is a low-cardinality enum, so a large class of "did the flash change something?" questions reduces to a duty-cycle delta on one row — the reason this is a committed harness rather than a one-off: **every** future can-bridge flash asks it again. The regression that motivated it is invisible in any single message: it is a 42.4 % OK↔WARN duty over a whole session. Default watchlist covers all three bus-naming eras (`bus*_health` / `can*_health` / `jugglebot_health`) and skips absent rows; `--keys` / `--markers` retarget it at any other row. Session discovery filters the rosbags root to **date-prefixed** dirs before sorting — a plain reverse-sort returns the `cone_test_*` and `Old naming scheme` dirs as "the newest sessions". Strictly offline and read-only (opens `.mcap` only; no node, no socket, no hardware) and needs NO ROS2 (`mcap_ros2` decodes the embedded schemas); needs the project venv. Degrades per-bag on an unreadable file and continues the sweep. `bags…` / `--root` / `--sessions N` / `--match` / `--keys` / `--markers` / `--top` / `--list-keys` / `--out` (timestamped JSON into `temp/probes/`). Exit 0 = all scanned, 1 = a bag was unreadable or carried no `/link_status`. | `logbook/2026-07-29-can3-bus-health-flap-hand-sensor-poller.md` — the operator flashed can-bridge FW_VERSION 4 (hand ball-sensor GPIO poller, `7dc347f` + `6cc38f7` + `73d70c6`) on 2026-07-29 and the sitting that followed flapped CAN3 bus health at a 42.4 % duty. Motivating bag: `/home/jetson/Desktop/rosbags/2026-07-29_22-37-06/`. Plan: `plans/archived/hand-ball-sensor.md` Phases 3–5. Runbook: `tests/hardware/session_hand_ball_sensor.md` § P5 (the on-board serial poller-ON/OFF A/B this is the offline counterpart to). Sibling: `archived/link_status_flash_control.py` |
| `capture_cup_cycle_refs.py` | **Freezes the CasADi/IPOPT reference cup cycles the numpy-only QP planner is measured against.** Runs the real `sim/juggle_planner/juggle_planner.py::plan_cup_cycle` over six pinned cycles (the two `tests/sim/test_demo_juggle_planner.py` fixture families + four grid points, level and tilted detach, periods 0.5-1.0 s) and writes their pos/vel/acc/jerk/t/catch_k/takeoff_vel to an `.npz`. The fixture exists because the reference **cannot be recomputed where the test runs**: `motion/trajectory/` is numpy-only Python 3.8 by architectural rule and CasADi lives only in the project venv, so T-U2's < 1 mm / < 10 mm/s parity gate would otherwise be unrunnable per-commit. Every case saturates a BOX in the reference solution on purpose — an equality-only solve would pass an unconstrained case and prove nothing. Committed fixture `data/cup_cycle_qp_refs.npz`; regenerate with **`--emit-fixture`**, venv interpreter only. | `logbook/2026-08-30-unified-7dof-planner-phase0-probes.md` (Decision 1 — the promotion of that entry's throwaway `/tmp/probe_qp_ref.py`) |
| `capture_v5_wire_fixtures.py` | **Froze the last PRE-v6 wire bytes as regression ground truth for the Phase 2 Setpoint widening** (unified-7dof-planner, 2026-09-01). At commit 2aaaae1 — the last `PROTOCOL_VERSION == 5` checkout — it drove the REAL `SetpointPump` and `KnotEmitter` over six pump cases (Mode-1 full lookahead, ext-fallback, no-lookahead, the torque-FF ramp/clamp sequence, a default-pump walk, an emitter-chained hold) and two emitter plans (hold + return-to-neutral), recording the exact 156-byte v5 `Setpoint` payloads, full CRC'd UDP frames, and `ipc._pack` msgpack bytes into `tests/teensy_link/data/v5_pump_wire_fixtures.json` + `tests/motion/data/v5_emitter_frame_fixtures.json` (a deliberate exception to the usual `tools/probes/data/` cut location — the consuming regression tests live beside their tiers). Those fixtures are READ-ONLY: T-U7/T-R1 pin the v6 pump/emitter's leg lanes bit-for-bit against them (`tests/teensy_link/test_v5_wire_regression.py`, `tests/motion/test_trajectory_emitter.py`) and T-R2 proves the live v6 codec rejects every recorded v5 frame. The script **refuses to run at any post-v6 checkout by design** (exit 2 on `PROTOCOL_VERSION != 5`) — it is a historical recipe, not a re-runnable gate; determinism was proven by byte-identical double capture before commit. | `logbook/2026-09-02-unified-7dof-planner-phase2-wire-v6.md` (the capture's canonical record — inventory, determinism proof, location-exception rationale; `2026-09-01-…-phase1-planner-core.md` for the pre-v6-boundary context) |
| `hand_overspeed_bag_probe.py` | Per hand THROW-stroke overspeed: how much faster the hand (and ball) leave than commanded. For every commanded hand-velocity peak in `/hand_telemetry` it reports commanded/measured peak (rev/s), `meas/cmd`, peak `|iq|`, and — from the matching `/balls` mocap track — ball launch speed and apex, `ball/cmd` and `ball/(meas*gain)` ("does the ball follow the encoder?"). `--cmd-source telemetry` (default) reads the commanded peak off the wire; `--cmd-source announcement` converts `/throw_announcements` `|v|` at `--mm-per-rev`, for Platform-Teensy-era bags. **Discovered 2026-09-14 mid-build and folded in**: `/hand_telemetry` is timing-unreliable by construction — the can-bridge coalesces its 500 Hz hand command echo to one frame per 100 Hz telemetry tick (`Teensy_code_canbridge/telemetry.cpp:230-280`) and `teensy_bridge_node._on_hand_cmd_echo` discards the echo's own `t_bridge_us`, so `_publish_hand_telemetry` stamps messages with the Jetson's 100 Hz poll clock instead (`teensy_bridge_node.py:2157-2172`, `:3486`) — inter-sample gaps run 2-20+ ms, not a clean 10 ms. The table is split accordingly: PRIMARY timing-robust columns (cmd/meas peak, `meas/cmd`, peak `|iq|`, the ball columns) first, ADVISORY timing-sensitive columns (fitted command delay, overspeed beyond delay, delay-compensated lag, mean ramp accel, and especially peak 10 ms commanded accel — a coalescing artifact, not a real command surge) last, headers suffixed `(adv)`. The finding this probe measures: the streamed hand lane sends **zero torque feedforward** (`leg_interp.cpp:1021` passes a literal `0.0f`), so overspeed beyond the command delay GROWS with commanded acceleration, unlike the retired Platform-Teensy engine's ~68% FF, which held it flat. Strictly offline and read-only (`.mcap` only, no node/socket/hardware, no ROS2 needed). `--bag` (dir or bare name under `~/Desktop/rosbags`) / `--since` / `--until` / `--cmd-source` / `--mm-per-rev` (default 32.567) / `--min-peak-rps` (default 60) / `--out` (timestamped CSV under `temp/probes/` by default). Validated against the scratch prototype on `2026-09-13_22-57-18` (three streamed strokes reproduce cmd/meas/delay/overspeed/iq within tolerance) and `2026-08-23_19-14-54 --cmd-source announcement --mm-per-rev 31.628` (Teensy-era tiers score `meas/cmd` ~0.95-1.02, peak iq 10-28 A). | `logbook/2026-09-14-skill-stack-r3-apex-ladder-prep.md` |
| `release_motion_bag_probe.py` | Per-release platform motion and ball launch from a sitting's bag: for every `jugglebot` ThrowAnnouncement, the mocap `Platform` tilt and xy from −0.6 to +0.2 s around the release, the announced launch velocity, and a g-fixed fit of the tracked free flight (launch velocity, apex, landing error, and the **release-lag** line: a parabola that extrapolates back to BELOW the announced release point means the ball separated after the plan's release knot — 20–40 ms late on every throw of 2026-09-27). `--hand-window T0 T1` dumps hand pos_cmd/pos_meas over a window (the 22:46 guard latch: cmd flat while the deviation grew). First use `logbook/2026-09-28-skill-stack-r4-sitting-1-analysis.md`. |
| `planned_release_motion.py` | Offline twin of `release_motion_bag_probe.py`: re-plans a hop and a self-toss (with and without a +20 mm re-aimed landing) through the REAL install chain and prints centroid xy / tilt / velocity and hand per knot from −0.6 to +0.2 s around every release, the planned cup velocity at the release knot, each install's report peaks and a HOLD verdict (worst centroid speed / displacement / tilt change over the 3 post-release knots). Used 2026-09-28 to show the plan's own post-release return (+33 mm/s at +0.05 s on the hop) and to size the post-release hold: 68 mm/s unheld → 13.36 at the first 75 ms cut → 2.75 at the shipped 50 ms (2 knots). |
| `hand_cascade_ff_model.py` | **Offline sibling of `hand_overspeed_bag_probe.py`: models the hand ODrive's own PASSTHROUGH position->velocity->torque cascade against a rigid-body hand+ball plant, BEFORE anything is flashed**, to predict whether the planned torque feedforward (`tau_ff = K * J_HAND * 2*pi * a_cmd`, `c2ff_spec.md`) actually closes the measured/commanded velocity gap. Builds real 0.9 m and 0.5 m apex self-toss attempts through `jugglebot.motion.skills.executor.install_segment` (the exact path `trajectory_node` drives), resamples each the way the CURRENT can-bridge firmware does (off-knot arrival phase, cubic Hermite, 500 Hz, no torque FF) and the way the FUTURE knot-aligned scheduled lane would, then drives the cascade at 8 kHz with ZOH between 500 Hz command ticks — gains, current limit and encoder-PLL bandwidth read from the flashed `odrive_pro_hand_config.json`, ball inertia (2.41e-6 kg*m^2) added only while the plan's own release/catch marks say the hand is holding a ball. Sweeps K in {0 (== today), 0.7, 1.0}. Reports peak meas/cmd velocity ratio, velocity at release, peak `|iq|` and peak position lag per case, and checks them against the pre-registered comparison in `c2ff_spec.md` (measured streamed FF=0: 1.02-1.27x, 23-54 A; Platform-Teensy ~70% FF era: 0.96-1.00x, 25-38 A) **without tuning the model to fit**. 2026-09-14 run: K=0 lands at 1.11-1.14x (inside the measured range); K=0.7 only reaches 1.04-1.05x, short of the <=1.00+-0.02 target — **verdict NOT SUPPORTED**, full torque authority (K=1.0, 1.02x) gets closest. Outputs timestamped CSV+md under `temp/probes/hand_cascade_ff/`. | `c2ff_spec.md` (unit U1) |
| `tracker_bag_replay.py` | **Production-faithful offline replay of the ball tracker.** Feeds a rosbag's `/mocap_data` (every marker, WITH its QTM label) and `/throw_announcements` through the SAME `BallTracker` `ball_tracker_node` builds from the SAME generated config, frame by frame in bag order, using each frame's own `MocapDataMulti.stamp` (the QTM frame time, 2026-09-20 — falls back to the bag's log time for older bags recorded before that field existed) as `current_time` — it re-implements no matching, gating or prediction, so a ball that confirms here confirms on the robot. This is the harness that surfaced the callback-time-jitter defect the stamp fixes: replaying `2026-09-18_16-16-17` with the bag's receipt (log) times converged 54/60 flights, but the LIVE node's callback-timestamped `/balls` stream converged only 33/60 under sitting load — reproduced by adding Gaussian jitter to the replay times (sigma 3/6/10 ms -> 55/43/23 of 60). Reports per announced ball: first CONFIRMED time relative to release, first landing-estimate time, the landing estimate **as it stands at the CATCH executor's own deadline** (`announced_landing − 0.278 s − lead`, the only number the executor actually consumes), landing xy error, frames tracked and final `BallStatus`; PASS = CONFIRMED within `--confirm-deadline-s` (default 0.25 s) with a landing estimate. Built to repro the 2026-09-15 sitting, where the node's unlabelled-only marker filter left all 13 balls ANNOUNCED because QTM had labelled the ball `Ball Butler - 1`: the pre-change code replays **0/13**, the fix replays **13/13** within 9 ms of release, and 2026-09-13's chained bag is unchanged at **1/3** (one physical ball, three announcements). Exists because every offline test in the repo fed the matcher synthetic *unlabelled* markers — the tests and the node agreed with each other and both disagreed with the mocap system. CSV + md under `temp/probes/`. **`--validate-landing` (added 2026-09-17)** scores landing-estimate ACCURACY instead: for each announced ball it fits an INDEPENDENT offline gravity-fixed parabola over the raw marker (z > 980 mm, two-pass 12 mm residual gate — same method as `late_catch_probe.py`), then reports the tracker's last-in-flight and dispatch-instant landing estimates minus that truth crossing, aggregated as bias/sd across one or more bags into `temp/probes/tracker_fit_validation_<tag>.md`. Built to validate `tracking/flight_fit.py` (the gravity-fixed batch landing fit that replaced the KF's 0.06-0.20 s-late extrapolation): on the 2026-09-17 bags it found and this fixed a real bug (`flight_fit.py`'s batch fit anchoring its reference time at the FIRST sample of a flight let real-ball drag curvature push the fitted position to the wrong side of the landing plane late in a flight, so `ballistics.predict_landing_state`'s smallest-positive-root pick occasionally snapped the estimate to ~10 ms after throw; anchoring at the LAST sample instead fixed it structurally). | `logbook/2026-09-15-tracker-all-markers-gated-to-expected-ball.md` |
| `feed_catch_bag_probe.py` | **Ground-truths BB-feed catch timing from a rosbag + the launch log.** For every flown reload feed (a `CATCH-AIM skill 1: source=schedule ... t_land=` line, parsed from the log — a throw BB refuses before release, e.g. `THROW_ABORTED_NOT_SETTLED`, never reaches this line and is excluded automatically): seeks the bag to a window around that feed's committed landing epoch (`mcap.reader` + `start_time`/`end_time`, ~1.2 s/6.4 s-window on a 427 MB bag this far in, vs. ~90 s/window for the sibling probes' full non-seeking `mcap_ros2.reader.read_ros2_messages` pass — this probe needs 14+ separate windows spread across a ~30 min bag, so the seek matters), ground-truths the ball's PHYSICAL release and landing from the RAW `label==''` `/mocap_data` marker track (a disjoint multi-target nearest-neighbour tracker, gap-stitched — the ball carries no QTM rigid-body label and BB's own throwing arm is also an unlabelled, moving marker for tens of ms after release), and reads the cushioning-stroke dive start/bottom and SEATED transition off `/hand_telemetry`. Prints the per-feed table (announced vs. observed release/landing, dive start/bottom, SEATED delay, hold tilt, caught) and a Decomposition (release-timing bias, flight-duration bias, and their sum — the landing bias) with mean/population-stdev. Confirmed on the 2026-09-30 R5 day-1 sitting (14 feeds, `~/Desktop/rosbags/2026-09-30_16-20-05`): release **+37.2 ms** (stdev 36.4), flight **+14.7 ms** (stdev 30.7), summing to a landing **+51.9 ms** late (stdev 15.4 — the tightest number of the three, since the two terms' per-feed method noise, a 14-47 ms-wide release-detection window, partially cancels in the sum). This underpins `ball_butler_node.py`'s `BB_RELEASE_PUSH_LAG_S` / `BB_FLIGHT_BIAS_S` constants and `tests/ros/test_ball_butler_node.py::TestReleaseLagCorrection` — re-run against a fresh sitting to re-measure them. JSON under `temp/probes/`. | — (promoted from a scratchpad probe during the 2026-09-30 sitting; predates a dedicated logbook entry) |
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

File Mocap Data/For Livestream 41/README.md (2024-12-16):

# Motion Capture Data

To save on space for anyone cloning this repo, these raw data files have been moved to Google Drive. You can find the files here:

https://drive.google.com/drive/folders/1mr2fu5Jrp4y6er7Wa5iQMWZVAHJSYiT6?usp=sharing

This dataset contains recordings of ball throwing captured in FBX, TSV, and MP4 formats. FBX files should be easier to work with 3D animation software, TSV should work for python/programming analysis, and the MP4 videos are to show what the recordings are each showing.

Unfortunately I haven't been able to get JSON exporting to work with unlabelled data. I'll look into this and will update this data if I ever figure it out...

Below, you will find a brief description template for each file in the dataset.

Feel free to do whatever you want with this data!

All recordings are taken at 300 FPS.

## File Descriptions

### 3_ball_juggling_uncut
**Length**: 39.60 sec (11879 frames)

**Description**: The full recording of me juggling 3 balls, including some high throws (which often briefly lose tracking), a drop at around 12.8 sec, and some very wide throws. There are intermittent erroneous markers, which I believe are from my pasty-white skin...

### 3_ball_juggling_cut
**Length**: 30.34 sec (9101 frames)

**Description**: The same recording as `3_ball_juggling_uncut` but with the start and end trimmed off.
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

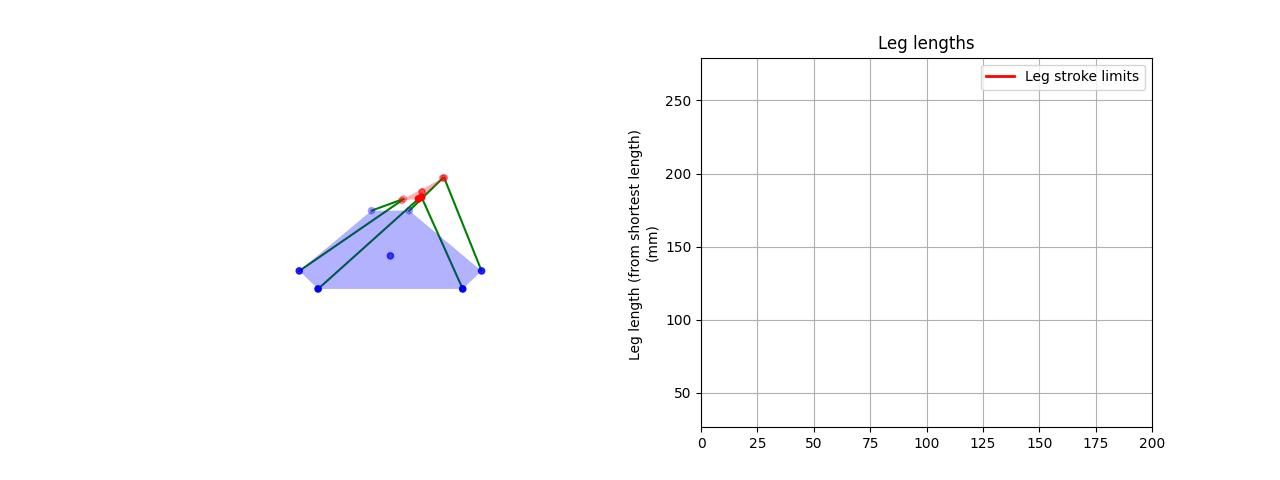
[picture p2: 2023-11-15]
simulations/stewart_platform_inverse_kinematics/stewart_platform_animation_with_leg_lengths.gif

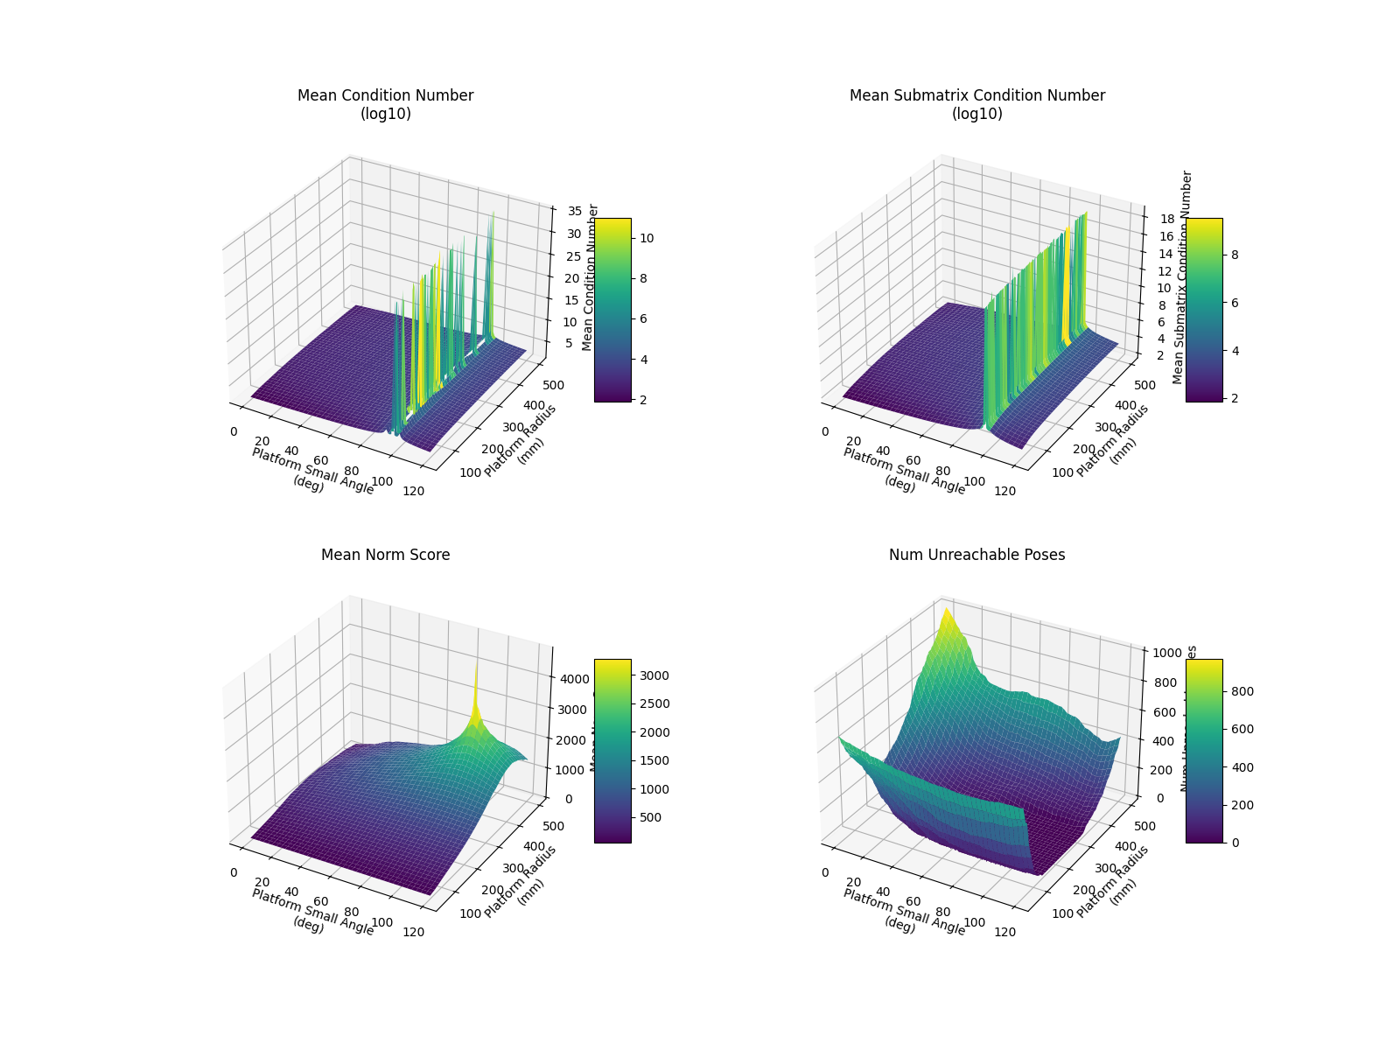
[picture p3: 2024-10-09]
simulations/stewart_platform_geometry_study/3d_surface_plots.png

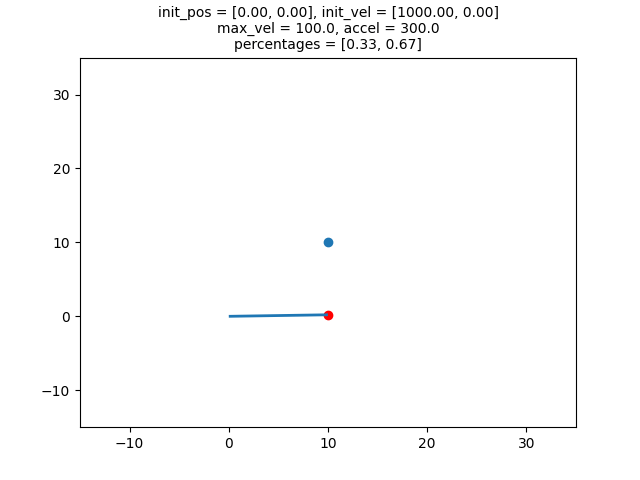
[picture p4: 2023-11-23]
simulations/target_approach_sim/target_approach_flower_pattern.gif

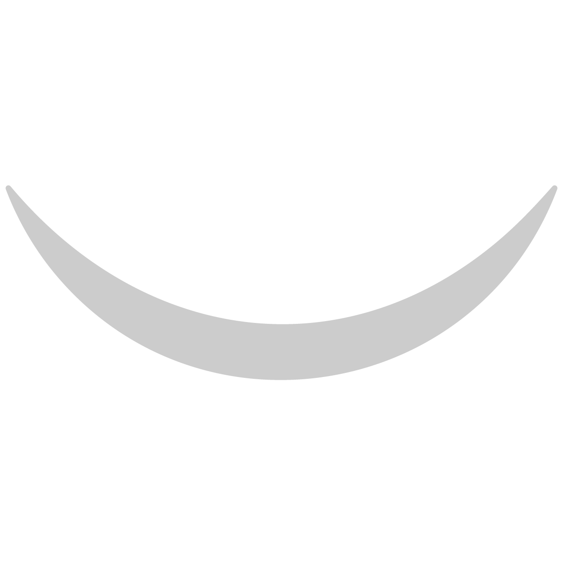
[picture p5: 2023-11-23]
simulations/trajectory_planning/hand.png

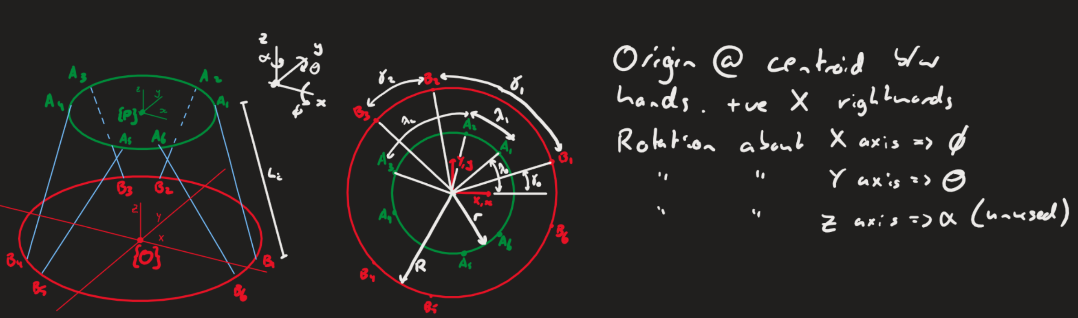
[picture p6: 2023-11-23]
simulations/stewart_platform_geometry_study/'main sketch'.png

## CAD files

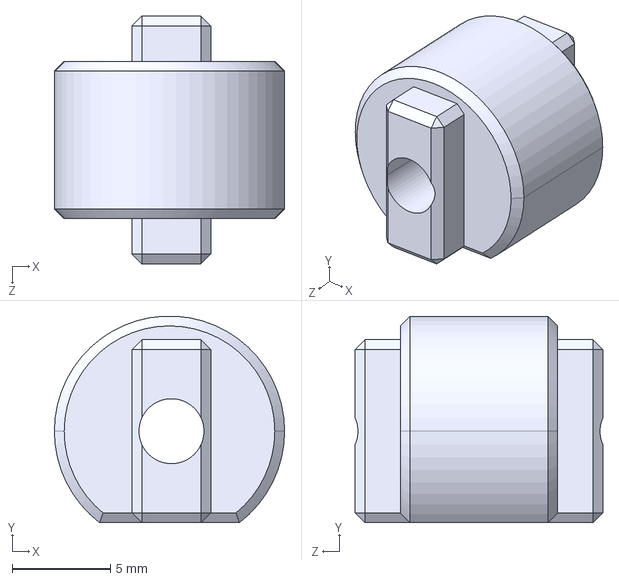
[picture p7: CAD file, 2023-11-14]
Folders for Specific Videos/PDJ #19 - Cad and Code for Linear Actuator Design/CAD/UpperLeg_Bearing_Spacer_0.1mm_Offset.STEP
11.7 x 10.5 x 12.6 mm

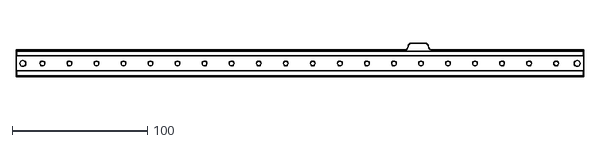
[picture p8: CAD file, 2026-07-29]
hand_sensor_pcb_rail/PCB Rail.dxf
420.0 x 25.0

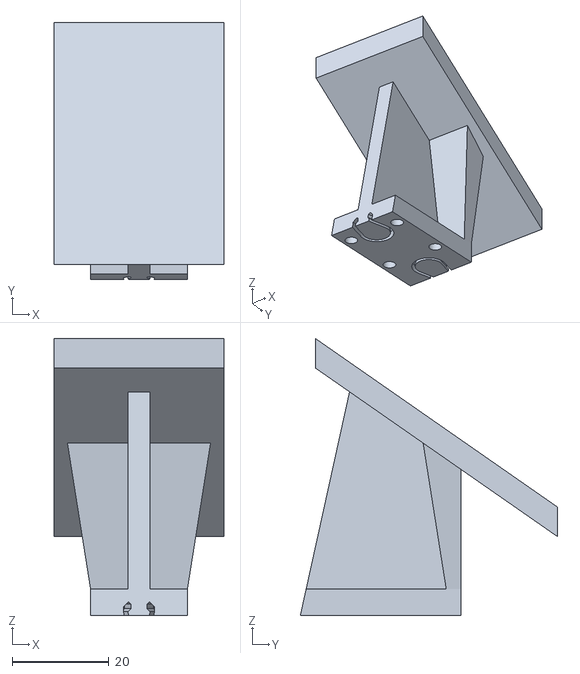
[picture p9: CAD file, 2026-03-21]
sim/model/meshes/Hand - Part 1.stl
35.0 x 53.1 x 57.2

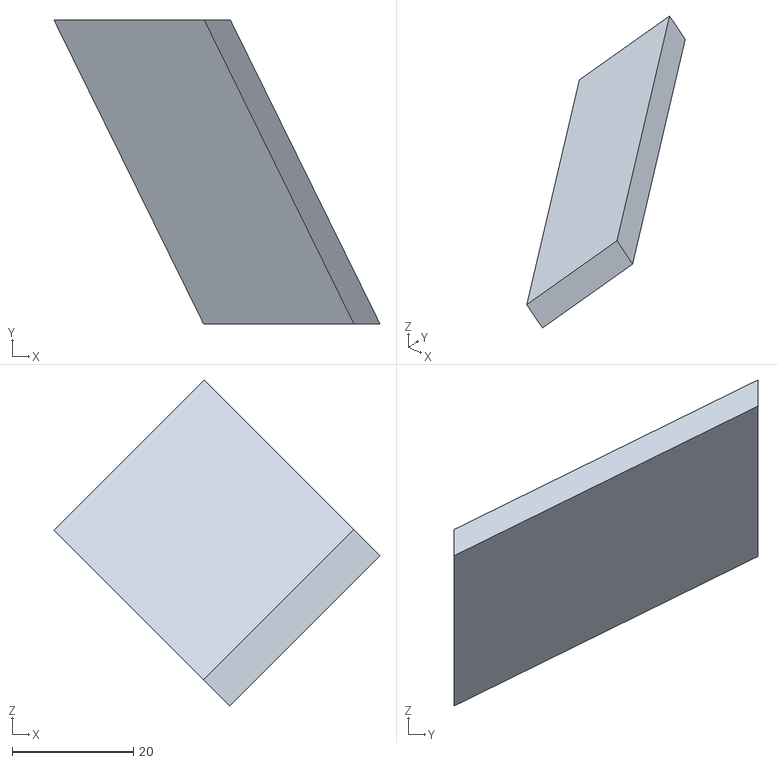
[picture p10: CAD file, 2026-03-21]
sim/model/meshes/Hand - Part 4.stl
53.7 x 50.0 x 53.7

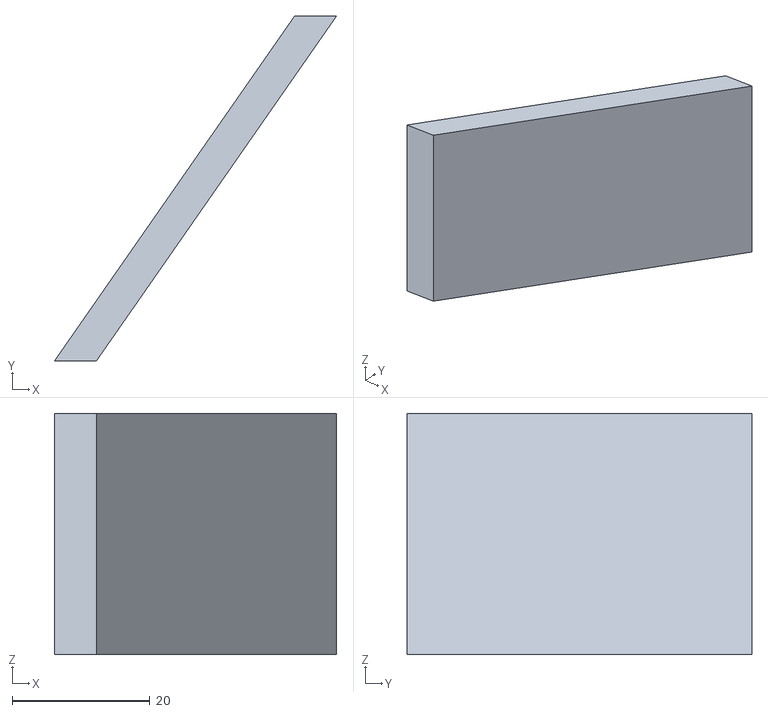
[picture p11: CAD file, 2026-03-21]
sim/model/meshes/Hand - Part 7.stl
40.9 x 50.0 x 35.0

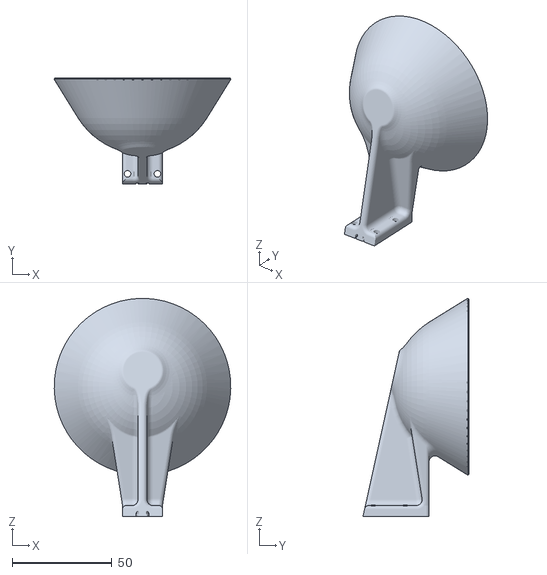
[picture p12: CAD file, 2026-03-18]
sim/model/meshes/hand.stl
88.4 x 53.1 x 109.2

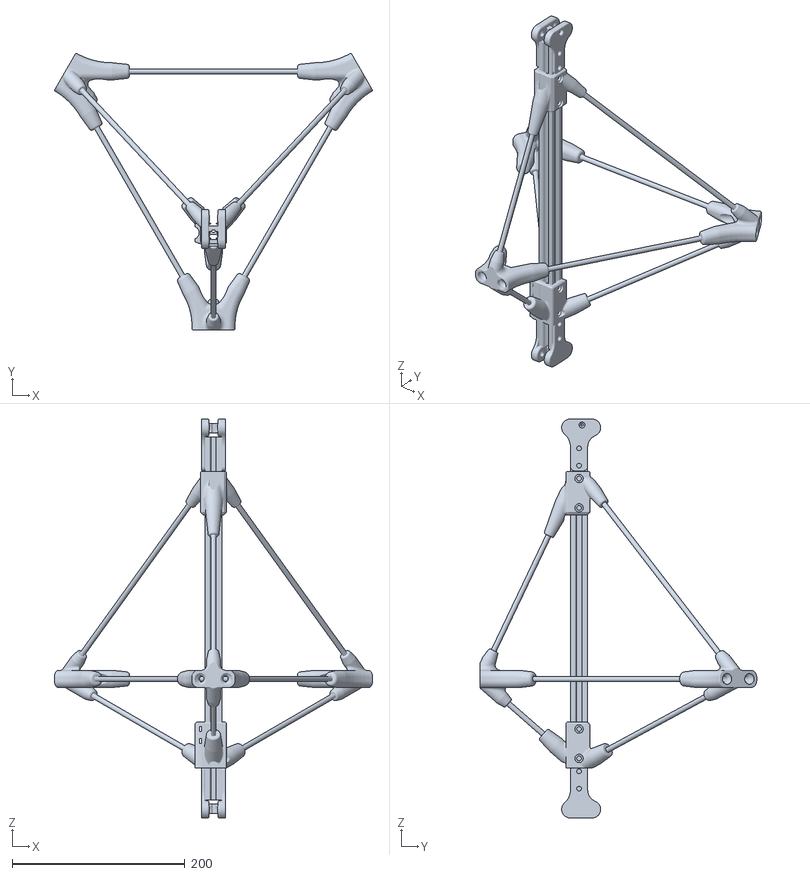
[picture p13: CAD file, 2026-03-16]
sim/model/meshes/platform.stl
368.3 x 320.1 x 461.9

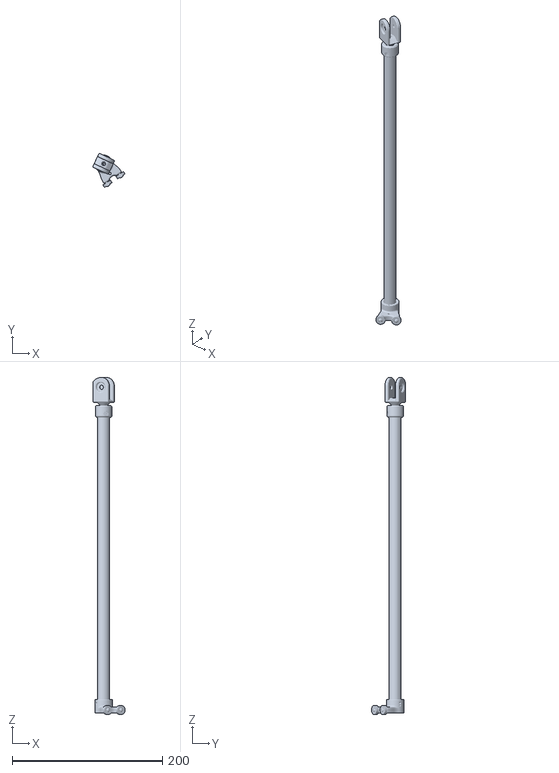
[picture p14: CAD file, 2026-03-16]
sim/model/meshes/leg_inner.stl
42.8 x 45.2 x 448.0

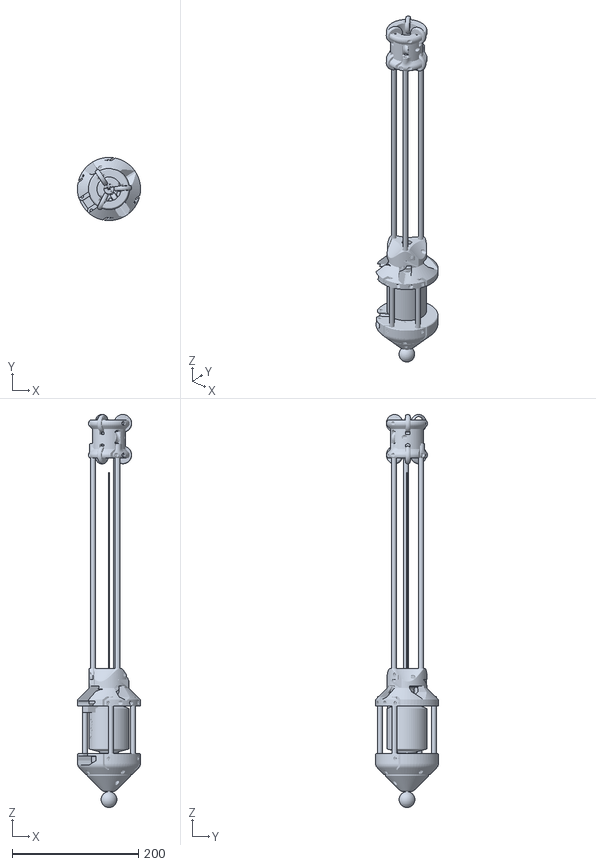
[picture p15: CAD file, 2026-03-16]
sim/model/meshes/leg_outer.stl
99.8 x 99.8 x 621.5

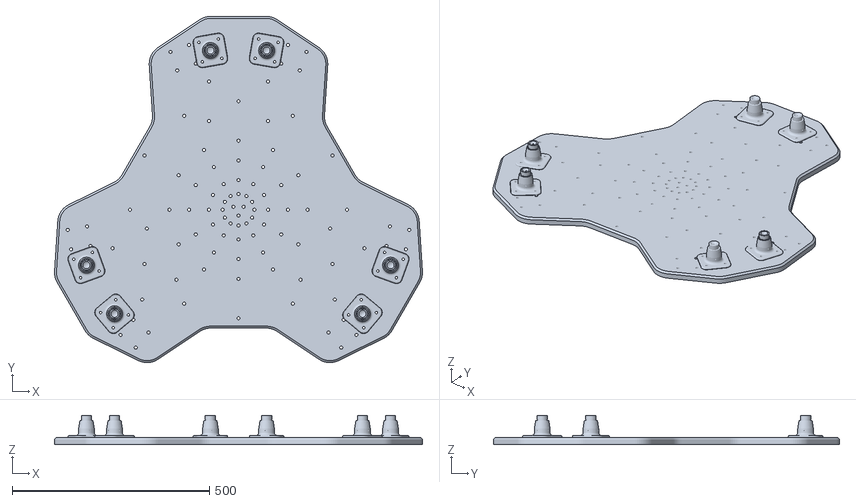
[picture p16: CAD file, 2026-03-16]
sim/model/meshes/base.stl
932.5 x 877.3 x 73.5

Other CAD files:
Folders for Specific Videos/PDJ #19 - Cad and Code for Linear Actuator Design/CAD/UpperLeg_Bearing_Spacer_Colinear.STEP
Folders for Specific Videos/PDJ #19 - Cad and Code for Linear Actuator Design/CAD/UpperLeg_Bearing_Spacer_0.3mm_Offset.STEP
sim/model/meshes/Hand - Part 8.stl
Folders for Specific Videos/PDJ #19 - Cad and Code for Linear Actuator Design/CAD/UpperLeg_Bearing_Spacer_0.2mm_Offset.STEP
sim/model/meshes/Hand - Part 2.stl
sim/model/meshes/Hand - Part 6.stl
sim/model/meshes/Hand - Part 3.stl
sim/model/meshes/Hand - Part 5.stl

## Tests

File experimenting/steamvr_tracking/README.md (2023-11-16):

This script's purpose is to get familiar with using SteamVR with my Tundra Trackers to get accurate real-time measurements of relative pose.

There are some fairly cool things that will become possible with this tech:
 - Accurate "external" pose measurements 
 - Getting more data of me juggling (tracking both/either the balls and my body)
 - Using the trackers to control the robot by syncing robot pose with tracker pose. Would be a great way to test the safety procedures (eg. not exceeding limits, not getting into structurally weak poses etc.)
 
THIS SCRIPT IS A WORK IN PROGRESS!

Note that this script will only work on Windows (and Mac?) machines due to its dependence on SteamVR. To use this script without having to connect a HMD, you'll have to modify your steamvr settings (Program Files (x86) > Steam > config > steamvr.vrsettings) by adding:

	"forcedHmd": "0",
	"requireHmd": false
	
to the "steamvr" section. An example steamvr.vrsettings file is included in this directory.

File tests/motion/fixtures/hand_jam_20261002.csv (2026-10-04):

# 2026-10-02 hand jam (bag 2026-10-02_18-11-14): /hand_telemetry rows | header stamp minus T=1790929469.795 (the guard-latch report) | joined to the latest /robot_state motor-6 sample (axis_state | active_errors). The age column is the PESSIMISTIC reconstruction (hand_jam_replay.py's --fixture-out/--fixture-window: age = hand row time minus the last /robot_state row at which the motor-6 diagnostic tuple changed -- see the module docstring). Decoded from the bag | not hand-edited.
t_minus_T_s | pos_cmd | vel_ff_cmd | pos_meas | vel_meas | iq_meas | axis_state | active_errors | diag_age_s
-0.8492 | 0.99200 | -14.2300 | 1.09978 | -16.9344 | -0.249 | 8 | 0 | 0.0150
-0.8417 | 0.86155 | -11.9100 | 0.95190 | -13.6195 | -1.009 | 8 | 0 | 0.0000
-0.8304 | 0.75265 | -9.9200 | 0.82866 | -11.8282 | -1.009 | 8 | 0 | 0.0122
-0.8169 | 0.66204 | -8.2600 | 0.72149 | -9.9220 | -1.009 | 8 | 0 | 0.0249
-0.8031 | 0.58641 | -6.9200 | 0.63425 | -7.9110 | -1.295 | 8 | 0 | 0.0389
-0.7876 | 0.46697 | -5.2400 | 0.51179 | -4.9717 | -3.869 | 8 | 0 | 0.0170
-0.7804 | 0.41659 | -4.8900 | 0.46083 | -5.0559 | -3.869 | 8 | 0 | 0.0077
-0.7708 | 0.36905 | -4.5600 | 0.40487 | -6.1427 | -1.232 | 8 | 0 | 0.0031
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

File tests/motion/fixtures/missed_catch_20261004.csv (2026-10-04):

attempt | label | t_rel_s | valid | raw | held | t_open_rel_s | t_close_rel_s
1 | miss | -0.4985 | True | True | True | -0.1964 | 0.39
1 | miss | -0.4863 | True | True | True | -0.1964 | 0.39
1 | miss | -0.479 | True | True | True | -0.1964 | 0.39
1 | miss | -0.4693 | True | True | True | -0.1964 | 0.39
1 | miss | -0.459 | True | True | True | -0.1964 | 0.39
1 | miss | -0.4488 | True | True | True | -0.1964 | 0.39
1 | miss | -0.4386 | True | True | True | -0.1964 | 0.39
1 | miss | -0.4266 | True | True | True | -0.1964 | 0.39
1 | miss | -0.4189 | True | True | True | -0.1964 | 0.39
1 | miss | -0.4078 | True | True | True | -0.1964 | 0.39
1 | miss | -0.3982 | True | False | True | -0.1964 | 0.39
1 | miss | -0.3883 | True | False | True | -0.1964 | 0.39
1 | miss | -0.3779 | True | True | True | -0.1964 | 0.39
1 | miss | -0.3683 | True | True | True | -0.1964 | 0.39
1 | miss | -0.357 | True | True | True | -0.1964 | 0.39
1 | miss | -0.3486 | True | True | True | -0.1964 | 0.39
1 | miss | -0.3384 | True | True | True | -0.1964 | 0.39
1 | miss | -0.3277 | True | True | True | -0.1964 | 0.39
1 | miss | -0.3178 | True | True | True | -0.1964 | 0.39
1 | miss | -0.3059 | True | True | True | -0.1964 | 0.39
1 | miss | -0.2984 | True | True | True | -0.1964 | 0.39
1 | miss | -0.2864 | True | True | True | -0.1964 | 0.39
1 | miss | -0.279 | True | True | True | -0.1964 | 0.39
1 | miss | -0.2684 | True | True | True | -0.1964 | 0.39
1 | miss | -0.2571 | True | False | True | -0.1964 | 0.39
1 | miss | -0.2476 | True | False | True | -0.1964 | 0.39
1 | miss | -0.2385 | True | False | True | -0.1964 | 0.39
1 | miss | -0.2278 | True | False | True | -0.1964 | 0.39
1 | miss | -0.2191 | True | False | True | -0.1964 | 0.39
1 | miss | -0.2073 | True | False | True | -0.1964 | 0.39
1 | miss | -0.1973 | True | False | True | -0.1964 | 0.39
1 | miss | -0.1876 | True | False | True | -0.1964 | 0.39
1 | miss | -0.1767 | True | False | False | -0.1964 | 0.39
1 | miss | -0.169 | True | False | False | -0.1964 | 0.39
1 | miss | -0.1579 | True | False | False | -0.1964 | 0.39
1 | miss | -0.1477 | True | False | False | -0.1964 | 0.39
1 | miss | -0.1389 | True | False | False | -0.1964 | 0.39
1 | miss | -0.1272 | True | False | False | -0.1964 | 0.39
1 | miss | -0.1193 | True | False | False | -0.1964 | 0.39
1 | miss | -0.108 | True | False | False | -0.1964 | 0.39
1 | miss | -0.0936 | True | False | False | -0.1964 | 0.39
1 | miss | -0.0859 | True | False | False | -0.1964 | 0.39
1 | miss | -0.0701 | True | False | False | -0.1964 | 0.39
1 | miss | -0.0664 | True | False | False | -0.1964 | 0.39
1 | miss | -0.0563 | True | False | False | -0.1964 | 0.39
1 | miss | -0.0489 | True | False | False | -0.1964 | 0.39
1 | miss | -0.0382 | True | False | False | -0.1964 | 0.39
1 | miss | -0.0281 | True | False | False | -0.1964 | 0.39
1 | miss | -0.0168 | True | False | False | -0.1964 | 0.39
1 | miss | -0.0043 | True | False | False | -0.1964 | 0.39
1 | miss | 0.0093 | True | False | False | -0.1964 | 0.39
1 | miss | 0.0162 | True | False | False | -0.1964 | 0.39
1 | miss | 0.0225 | True | False | False | -0.1964 | 0.39
1 | miss | 0.0362 | True | False | False | -0.1964 | 0.39
1 | miss | 0.0467 | True | False | False | -0.1964 | 0.39
1 | miss | 0.0541 | True | False | False | -0.1964 | 0.39
1 | miss | 0.0664 | True | False | False | -0.1964 | 0.39
1 | miss | 0.0794 | True | False | False | -0.1964 | 0.39
1 | miss | 0.0826 | True | False | False | -0.1964 | 0.39
1 | miss | 0.0926 | True | False | False | -0.1964 | 0.39
1 | miss | 0.1053 | True | False | False | -0.1964 | 0.39
1 | miss | 0.111 | True | False | False | -0.1964 | 0.39
1 | miss | 0.1219 | True | False | False | -0.1964 | 0.39
1 | miss | 0.135 | True | False | False | -0.1964 | 0.39
1 | miss | 0.1465 | True | False | False | -0.1964 | 0.39
1 | miss | 0.1533 | True | False | False | -0.1964 | 0.39
1 | miss | 0.1656 | True | False | False | -0.1964 | 0.39
1 | miss | 0.1754 | True | False | False | -0.1964 | 0.39
1 | miss | 0.1825 | True | False | False | -0.1964 | 0.39
1 | miss | 0.1927 | True | False | False | -0.1964 | 0.39
1 | miss | 0.2016 | True | False | False | -0.1964 | 0.39
1 | miss | 0.2135 | True | False | False | -0.1964 | 0.39
1 | miss | 0.221 | True | False | False | -0.1964 | 0.39
1 | miss | 0.2334 | True | False | False | -0.1964 | 0.39
1 | miss | 0.2428 | True | False | False | -0.1964 | 0.39
1 | miss | 0.2525 | True | False | False | -0.1964 | 0.39
1 | miss | 0.2613 | True | False | False | -0.1964 | 0.39
1 | miss | 0.2722 | True | False | False | -0.1964 | 0.39
1 | miss | 0.2837 | True | False | False | -0.1964 | 0.39
1 | miss | 0.2991 | True | False | False | -0.1964 | 0.39
1 | miss | 0.3079 | True | False | False | -0.1964 | 0.39
1 | miss | 0.313 | True | False | False | -0.1964 | 0.39
1 | miss | 0.3226 | True | False | False | -0.1964 | 0.39
1 | miss | 0.3311 | True | False | False | -0.1964 | 0.39
1 | miss | 0.3453 | True | False | False | -0.1964 | 0.39
1 | miss | 0.3524 | True | False | False | -0.1964 | 0.39
1 | miss | 0.3633 | True | False | False | -0.1964 | 0.39
1 | miss | 0.3744 | True | False | False | -0.1964 | 0.39
1 | miss | 0.3838 | True | False | False | -0.1964 | 0.39
1 | miss | 0.3929 | True | False | False | -0.1964 | 0.39
1 | miss | 0.4051 | True | False | False | -0.1964 | 0.39
1 | miss | 0.4167 | True | False | False | -0.1964 | 0.39
1 | miss | 0.4243 | True | False | False | -0.1964 | 0.39
1 | miss | 0.4314 | True | False | False | -0.1964 | 0.39
1 | miss | 0.4411 | True | False | False | -0.1964 | 0.39
1 | miss | 0.4514 | True | False | False | -0.1964 | 0.39
1 | miss | 0.4623 | True | False | False | -0.1964 | 0.39
1 | miss | 0.4746 | True | False | False | -0.1964 | 0.39
1 | miss | 0.4838 | True | False | False | -0.1964 | 0.39
1 | miss | 0.4946 | True | False | False | -0.1964 | 0.39
1 | miss | 0.5067 | True | False | False | -0.1964 | 0.39
1 | miss | 0.5132 | True | False | False | -0.1964 | 0.39
1 | miss | 0.5221 | True | False | False | -0.1964 | 0.39
1 | miss | 0.5326 | True | False | False | -0.1964 | 0.39
1 | miss | 0.5463 | True | False | False | -0.1964 | 0.39
1 | miss | 0.5521 | True | False | False | -0.1964 | 0.39
1 | miss | 0.5666 | True | False | False | -0.1964 | 0.39
1 | miss | 0.5726 | True | False | False | -0.1964 | 0.39
1 | miss | 0.5838 | True | False | False | -0.1964 | 0.39
1 | miss | 0.5941 | True | False | False | -0.1964 | 0.39
1 | miss | 0.6034 | True | False | False | -0.1964 | 0.39
1 | miss | 0.614 | True | False | False | -0.1964 | 0.39
1 | miss | 0.6208 | True | False | False | -0.1964 | 0.39
1 | miss | 0.631 | True | False | False | -0.1964 | 0.39
1 | miss | 0.6433 | True | False | False | -0.1964 | 0.39
1 | miss | 0.6535 | True | False | False | -0.1964 | 0.39
1 | miss | 0.668 | True | False | False | -0.1964 | 0.39
1 | miss | 0.6732 | True | False | False | -0.1964 | 0.39
1 | miss | 0.6808 | True | False | False | -0.1964 | 0.39
1 | miss | 0.6936 | True | False | False | -0.1964 | 0.39
1 | miss | 0.7024 | True | True | True | -0.1964 | 0.39
1 | miss | 0.7123 | True | True | True | -0.1964 | 0.39
1 | miss | 0.726 | True | False | True | -0.1964 | 0.39
1 | miss | 0.7306 | True | False | True | -0.1964 | 0.39
1 | miss | 0.7442 | True | True | True | -0.1964 | 0.39
1 | miss | 0.7512 | True | True | True | -0.1964 | 0.39
1 | miss | 0.7685 | True | True | True | -0.1964 | 0.39
1 | miss | 0.7758 | True | True | True | -0.1964 | 0.39
1 | miss | 0.7821 | True | True | True | -0.1964 | 0.39
1 | miss | 0.7936 | True | True | True | -0.1964 | 0.39
1 | miss | 0.8022 | True | True | True | -0.1964 | 0.39
1 | miss | 0.8139 | True | True | True | -0.1964 | 0.39
1 | miss | 0.8251 | True | True | True | -0.1964 | 0.39
1 | miss | 0.8326 | True | True | True | -0.1964 | 0.39
1 | miss | 0.846 | True | True | True | -0.1964 | 0.39
1 | miss | 0.8517 | True | True | True | -0.1964 | 0.39
1 | miss | 0.8664 | True | True | True | -0.1964 | 0.39
1 | miss | 0.8738 | True | True | True | -0.1964 | 0.39
1 | miss | 0.8806 | True | False | True | -0.1964 | 0.39
1 | miss | 0.8909 | True | False | True | -0.1964 | 0.39
1 | miss | 0.9075 | True | False | True | -0.1964 | 0.39
1 | miss | 0.9174 | True | False | True | -0.1964 | 0.39
1 | miss | 0.9258 | True | False | True | -0.1964 | 0.39
1 | miss | 0.9308 | True | False | True | -0.1964 | 0.39
1 | miss | 0.944 | True | False | True | -0.1964 | 0.39
1 | miss | 0.9531 | True | False | True | -0.1964 | 0.39
1 | miss | 0.9609 | True | False | False | -0.1964 | 0.39
1 | miss | 0.9724 | True | False | False | -0.1964 | 0.39
1 | miss | 0.9817 | True | False | False | -0.1964 | 0.39
1 | miss | 0.9934 | True | False | False | -0.1964 | 0.39
2 | miss | -0.4998 | True | True | True | -0.2057 | 0.39
2 | miss | -0.4888 | True | True | True | -0.2057 | 0.39
2 | miss | -0.4804 | True | True | True | -0.2057 | 0.39
2 | miss | -0.4686 | True | True | True | -0.2057 | 0.39
2 | miss | -0.455 | True | True | True | -0.2057 | 0.39
2 | miss | -0.4499 | True | True | True | -0.2057 | 0.39
2 | miss | -0.4388 | True | True | True | -0.2057 | 0.39
2 | miss | -0.4297 | True | True | True | -0.2057 | 0.39
2 | miss | -0.4184 | True | True | True | -0.2057 | 0.39
2 | miss | -0.4098 | True | True | True | -0.2057 | 0.39
2 | miss | -0.399 | True | False | True | -0.2057 | 0.39
2 | miss | -0.3894 | True | False | True | -0.2057 | 0.39
2 | miss | -0.3796 | True | False | True | -0.2057 | 0.39
2 | miss | -0.3696 | True | False | True | -0.2057 | 0.39
2 | miss | -0.3597 | True | True | True | -0.2057 | 0.39
2 | miss | -0.3495 | True | True | True | -0.2057 | 0.39
2 | miss | -0.3393 | True | True | True | -0.2057 | 0.39
2 | miss | -0.3289 | True | True | True | -0.2057 | 0.39
2 | miss | -0.3133 | True | False | True | -0.2057 | 0.39
2 | miss | -0.3015 | True | False | True | -0.2057 | 0.39
2 | miss | -0.2893 | True | False | True | -0.2057 | 0.39
2 | miss | -0.2782 | True | True | True | -0.2057 | 0.39
2 | miss | -0.2699 | True | True | True | -0.2057 | 0.39
2 | miss | -0.26 | True | False | True | -0.2057 | 0.39
2 | miss | -0.2447 | True | False | True | -0.2057 | 0.39
2 | miss | -0.2399 | True | False | True | -0.2057 | 0.39
2 | miss | -0.2287 | True | False | True | -0.2057 | 0.39
2 | miss | -0.2123 | True | False | True | -0.2057 | 0.39
2 | miss | -0.1987 | True | False | True | -0.2057 | 0.39
2 | miss | -0.1887 | True | False | True | -0.2057 | 0.39
2 | miss | -0.1803 | True | False | False | -0.2057 | 0.39
2 | miss | -0.1695 | True | False | False | -0.2057 | 0.39
2 | miss | -0.1595 | True | False | False | -0.2057 | 0.39
2 | miss | -0.1495 | True | False | False | -0.2057 | 0.39
2 | miss | -0.1403 | True | False | False | -0.2057 | 0.39
2 | miss | -0.1283 | True | False | False | -0.2057 | 0.39
2 | miss | -0.1193 | True | False | False | -0.2057 | 0.39
2 | miss | -0.1052 | True | False | False | -0.2057 | 0.39
2 | miss | -0.0985 | True | False | False | -0.2057 | 0.39
2 | miss | -0.0903 | True | False | False | -0.2057 | 0.39
2 | miss | -0.0769 | True | False | False | -0.2057 | 0.39
2 | miss | -0.0676 | True | False | False | -0.2057 | 0.39
2 | miss | -0.0599 | True | False | False | -0.2057 | 0.39
2 | miss | -0.0486 | True | False | False | -0.2057 | 0.39
2 | miss | -0.0397 | True | False | False | -0.2057 | 0.39
2 | miss | -0.028 | True | False | False | -0.2057 | 0.39
2 | miss | -0.0191 | True | False | False | -0.2057 | 0.39
2 | miss | -0.0096 | True | False | False | -0.2057 | 0.39
2 | miss | 0.0012 | True | False | False | -0.2057 | 0.39
2 | miss | 0.0104 | True | False | False | -0.2057 | 0.39
2 | miss | 0.0207 | True | False | False | -0.2057 | 0.39
2 | miss | 0.0315 | True | False | False | -0.2057 | 0.39
2 | miss | 0.0415 | True | False | False | -0.2057 | 0.39
2 | miss | 0.0506 | True | False | False | -0.2057 | 0.39
2 | miss | 0.0608 | True | False | False | -0.2057 | 0.39
2 | miss | 0.0714 | True | False | False | -0.2057 | 0.39
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

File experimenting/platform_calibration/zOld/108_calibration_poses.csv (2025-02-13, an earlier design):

leg_length_1 | leg_length_2 | leg_length_3 | leg_length_4 | leg_length_5 | leg_length_6 | position_x | position_y | position_z | orientation_x | orientation_y | orientation_z | orientation_w
1.6767652 | 1.22339 | 1.2163502 | 1.8778893 | 1.9548622 | 1.8523405 | 5.68169641494751 | -2.3655965328216553 | 751.5284423828125 | 0.07218229137154475 | -0.013575722707873406 | 0.006013082209858942 | 0.9972809392557858
1.5469415 | 2.1703525 | 2.1010568 | 1.2076908 | 1.2095655 | 1.545841 | 8.406487464904785 | 3.568390130996704 | 751.1178588867188 | -0.0919299520829081 | 0.03635264424291107 | 0.005202661216348001 | 0.9950880845655573
2.0621414 | 1.0493175 | 0.9823414 | 1.6498295 | 1.7318453 | 2.3181171 | 6.4843926429748535 | -4.4705705642700195 | 750.7251586914062 | 0.10752845215950368 | 0.05502647244370001 | 0.01637553441468794 | 0.9925429691122364
1.4649101 | 2.380069 | 2.3727224 | 1.9579941 | 1.8775972 | 1.5451086 | 5.830663681030273 | 3.7542002201080322 | 774.5948486328125 | -0.08090745338653997 | -0.04136823655985619 | 0.011825401576994453 | 0.9957925528126206
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

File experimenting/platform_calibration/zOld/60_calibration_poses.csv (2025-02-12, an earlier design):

leg_length_1 | leg_length_2 | leg_length_3 | leg_length_4 | leg_length_5 | leg_length_6 | position_x | position_y | position_z | orientation_x | orientation_y | orientation_z | orientation_w
1.6924095 | 1.8641262 | 1.9187604 | 2.3058589 | 2.2879848 | 1.7136728 | 5.756841659545898 | 4.984894275665283 | 777.7637329101562 | 0.011560742918575985 | -0.06039547184600476 | -0.004131312827800862 | 0.9980990327169579
1.9185467 | 2.0258102 | 2.0289862 | 1.9480077 | 1.937399 | 1.9146596 | 6.885221004486084 | 5.2444305419921875 | 777.6060791015625 | -0.012575656591810624 | -0.002622379640111303 | -0.003108838523781003 | 0.9999126530289156
1.6230145 | 1.924858 | 1.9824907 | 2.3276637 | 2.28652 | 1.6421396 | 5.012059688568115 | 5.6044602394104 | 777.8565063476562 | 0.0007234557173561495 | -0.06856890354937852 | -0.002747926214537486 | 0.9976423380575546
1.623869 | 2.3397121 | 2.3657153 | 1.953808 | 1.8874093 | 1.6078416 | 5.766874313354492 | 6.904941082000732 | 777.8479614257812 | -0.07080883715892614 | -0.03030009065509022 | -0.0012680121919545434 | 0.9970287945777968
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

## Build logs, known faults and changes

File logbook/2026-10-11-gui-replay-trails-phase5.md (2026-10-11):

---
title: GUI replay Phase 5 - balls and ribbon trails in the 3D scene, live and replay
type: feature
date: 2026-10-11
status: resolved
phase: "gui-rosbag-replay - Phase 5 (balls and trails)"
related_plan: gui-rosbag-replay.md
files_changed:
  - logbook/2026-10-11-gui-replay-trails-phase5.md
  - logbook/INDEX.md
  - plans/active/gui-rosbag-replay.md
  - ros_ws/gui/css/viewer.css
  - ros_ws/gui/js/main.js
  - ros_ws/gui/js/marker-palette.js
  - ros_ws/gui/js/mocap-markers.js
  - ros_ws/gui/js/replay/mode.js
  - ros_ws/gui/js/replay/policy.js
  - ros_ws/gui/js/replay/trail-window.js
  - ros_ws/gui/js/replay/wiring.js
  - ros_ws/gui/js/trail-feed.js
  - ros_ws/gui/js/trail-settings-ui.js
  - ros_ws/gui/js/trail-settings.js
  - ros_ws/gui/js/trails-scene.js
  - ros_ws/gui/js/trails.js
  - ros_ws/gui/replay/schema.py
  - tests/ros/js/replay_mode_harness.js
  - tests/ros/js/replay_trail_window_harness.js
  - tests/ros/js/trail_feed_harness.js
  - tests/ros/js/trail_layer_harness.js
  - tests/ros/test_gui_replay_mode.py
  - tests/ros/test_gui_replay_trail_window.py
  - tests/ros/test_gui_trail_feed.py
  - tests/ros/test_gui_trail_layer.py
  - tests/ros/test_gui_trails_wiring.py
subsystem:
  - gui
tags:
  - feature
  - testing
---

# GUI replay Phase 5 - balls and ribbon trails in the 3D scene, live and replay

## Summary

The 3D scene now draws the tracked balls (`/balls`) as spheres and a fading ribbon trail behind every ball and every
mocap marker, live and in replay, with one "Trail length" setting (0..5 s, default 1 s) in the scene menu beside the
camera presets. This builds the owner's picks on the ticket 04 prototype (ribbon, dim AND thin with age, label colours
for markers, a hue per ball id, fade over the tail). Replay feeds the trails from the resident chunk columns at
recorded rate, not from the engine's gated dispatch. The design is § Phase 5 of `plans/active/gui-rosbag-replay.md`.

## Discussion

The survey before the build forced four decisions the prototype could not see, because it ran on synthetic data.
Each is recorded with its cause in the plan (D1-D4).

- **D1, ball tracks end on staleness as well as absence.** `ball_tracker_node` publishes `/balls` only while a ball
  is tracked, so the last ball never sees a message without its id. A track also ends, at its last message time, after
  150 ms of silence. The audit then found the same rule must run at the start of every `/balls` message, or a rebuilt
  replay window that spans a gap ends the old track at the new message's time.
- **D2, 10 ms per-track decimation.** Real `/mocap_data` is recorded at about 197 Hz (busy bag `2026-10-02_12-43-28`),
  twice what the prototype's ring was sized for. Decimating keeps the 640-sample ring and halves the work.
- **D3, the duplicate-trail rule.** The tracked ball is also an unlabelled mocap marker. An unlabelled marker within
  40 mm of a fresh ball gets no trail and no nearest-neighbour slot.
- **D4, one trail writer per mode.** Replay dispatches `/mocap_data` through the live handler, so its trail lines are
  skipped while `clock.isReplay()`. The columns window is then the only writer and supplies the render time, since a
  scrub never moves `clock.now()`.

Two tradeoffs were accepted. The layer re-uploads a written track's whole buffer (about 70 KB) instead of a per-sample
update range, because the range objects allocate per push. And trail times are float32 relative to a track's first
sample, which loses fade resolution only for a track alive for about a day.

The smoke on the busy bag overturned one sizing assumption. The bag carries 21 persistent marker tracks and peaks at
46 live tracks at a 5 s tail and 8x, so the 32-track pool dropped hundreds of pushes. The pool is 64.

## Fix

- New modules: `trails.js` (the ribbon layer), `trail-feed.js` (keying and D1-D3), `trail-settings.js` and its UI row,
  `marker-palette.js` (the label palette moved out of `mocap-markers.js`), `trails-scene.js` (singleton, ball spheres,
  one `onFrame` render), `replay/trail-window.js` (append for a forward step within the tail, rebuild otherwise).
- `main.js` subscribes `/balls` at 20 ms and feeds the trails live only; `schema.py` moves `/balls` from PLANNED to
  SUBSCRIBED. `mode.js` creates the window on entry, forwards both engine hooks, and makes the seek pre-roll cover the
  tail.
- Audit fixes (one pass, 2026-10-11): tail 0 no longer hides the replay ball spheres (the window feeds at least the
  150 ms staleness span); a vacuous layer test now pins "no line across a revived track's gap"; the nearest-neighbour
  search no longer reuses a slot within one message; a wall-clock bound left the parallel gate.

## Verification

- Scoped (`pytest tests/ros/test_gui_trail_*.py tests/ros/test_gui_replay_trail_window.py tests/ros/test_gui_trails_wiring.py tests/ros/test_gui_replay_mode.py tests/ros/test_gui_clock_contract.py -q`, run 2026-10-11): **49 passed**.
- Headless Chromium smoke on the busy bag (run 2026-10-11, driver kept in the session scratchpad): 7 of 8 items PASS
  (live settings row, seeks, 1x and 8x play, reverse and scrub, tail 0 and 5 s, exit); heap after GC 6.5 MB before
  entry, 27.0 MB after 30 s of play, 8.8 MB after exit. The paused-replay allocation check was inconclusive: garbage
  grows equally with trails on and off, so it comes from elsewhere. The screenshot shows a coloured ribbon arcing from
  Ball Butler with the ball sphere at its head.
- Replay rebuild of a 5 s window on the busy bag under node: median 1.44 ms, max 8.8 ms (1,926 records).
- Full gate (`./run_tests.sh`, run 2026-10-11 in the `Jugglebot-replay` worktree, log `temp/logs/gate_phase5_2026-10-11.log`): **6601 passed, 9 skipped; serial 3 passed; RESULT PASS** (306 s).

## Outcome

Phase 5 is software-complete. Open for the owner: a live throw to check that D3's 40 mm gate holds at the live
throttles (`/mocap_data` 50 ms, `/balls` 20 ms stamp at receipt, so a fast ball may sit beyond 40 mm of its own
marker and grow a duplicate trail; the audit could not confirm this without live data), and a look at the colours
and widths in the owner's own browser.

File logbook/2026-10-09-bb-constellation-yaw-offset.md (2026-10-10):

---
title: Ball Butler's yaw offset and position come from the whole calibration sweep, with the heartbeat lag fitted per sweep and a fixed E(y), against a 7-marker body template; a consistency gate refuses a frame change unless bb_moved is set
type: feature
date: 2026-10-09
status: in-progress
phase: "two-ball-skill-stack — R5 (Ball Butler calibration)"
related_plan: two-ball-skill-stack.md
files_changed:
  - ros_ws/src/jugglebot/jugglebot/bb_calibration.py
  - ros_ws/src/jugglebot/jugglebot/mocap_node.py
  - ros_ws/src/jugglebot/resources/bb_marker_template.json
  - ros_ws/docs/choreography.md
  - tests/ros/test_bb_calibration_constellation.py
  - tests/ros/test_mocap_node_yaw_gate.py
  - tests/ros/test_perception_console_lines.py
  - logbook/2026-10-09-bb-constellation-yaw-offset.md
  - logbook/INDEX.md
  - logbook/2026-10-10-bb-base-marker-frame.md
subsystem:
  - ros
  - tracking
tags:
  - kinematics
  - testing
---

# Ball Butler's yaw offset and position come from the whole calibration sweep, with the heartbeat lag fitted per sweep and a fixed E(y), against a 7-marker body template; a consistency gate refuses a frame change unless bb_moved is set

## Problem

`bb_calibration.calculate_yaw_offset` read BB's yaw offset from ONE marker (QTM 4) at 117.6 mm from the axis point that the sweep fitted, so 1 mm of axis error was 0.49° of yaw. Two calibrations on 2026-10-09 with BB untouched stored 0.208° (session A, `20261009T002142_931068Z`, the frame `throw_affine_correction.json` was fitted in) and 0.681° (session B, `20261009T031319_612936Z`); session B's throws landed −8 mm sideways at 1 m (`~/bb_calibration_sessions/yaw_offset_investigation_20261009/REPORT.md`).

## Superseded first design (same day, commit ceea98c7)

The first fix read the offset from the sweep's stationary yaw-0 pause only: per-marker medians of the hold, a label-free 2D match to a 4-marker co-planar template, σ floored at a 0.13° hold scatter, gauge pinned so the 7-sweep bag's pauses averaged 0.208°. It was no more repeatable per sweep (SD 0.095°) than the anchor (0.090°), it saw only 3 markers at the pause, and a second investigation (`~/bb_calibration_sessions/bb_placement_reinvestigation_20261009/REPORT.md`) showed its pin was taken on frames where the parked pose reconstructs non-rigidly. It also excluded the moving sweep on the strength of an "~80 ms" heartbeat lag treated as a constant, and dropped the off-plane markers QTM 1/2 on a claim ("they distort at yaw 0") that was an instrument effect at one pose. The owner rejected it. This entry replaces it; nothing of the pause estimator, its 0.13° floor, the 80 ms constant or the QTM 1/2 exclusion remains.

## Discussion

**Why the whole sweep.** The moving sweep has ~37 heartbeat samples spread over 0–125° per sweep, where the pause has one pose. What stood in the way was the heartbeat's lag: it is unstamped, and its yaw passes three free-running 10 Hz stages, so it lags the mocap frames by a per-session amount (80–85 ms in the 7-sweep bag, 94–97 ms in A). Fitting that lag per sweep is cheap and well conditioned: a lag error shows as ±ω·δτ with opposite signs on the outbound and return legs.

**Decisions (made before the work; recorded here):**
1. Estimator = whole sweep, lag fitted per sweep, all visible yaw-stage markers as one rigid body, a fixed E(y), one offset per sweep, loud failures.
2. Position from the body model's axis point over the sweep; the arc fit stays as a cross-check; tilt from the arc fit as before.
3. Template rebuilt yaw-balanced from all 7 markers of A, B and the 7-sweep bag, with E(y) and the gauge in it. Gauge pinned to session A's frame: A's own data must read 0.208°. ONE number (`gauge.pinned_yaw_offset_deg`) is the owner's adjustment.
4. σ = per-sweep formal error ⊕ out-of-sample repeatability (leave-sweeps-out on the 7 sweeps). No per-frame SD, no pause floor.
5. Gate: no state file → accept, persist, WARN; afterwards refuse |Δyaw| > max(3σ, 0.15°) (since 2026-10-10: 3·√(σ_new² + σ_ref²), see 2026-10-09-bb-calibration-heartbeat-yaw-wrap), |Δaxis| > 1.5 mm, or template residual > 0.5 mm; the one-shot `bb_moved` resets the reference (also after a QTM recalibration).
6. Drop the 80 ms constant, the pause floor, the QTM 1/2-at-yaw-0 claim.

**Findings made during the work that changed the code (each checked on the bags before acting):**
- **Session B's heartbeat is a two-age mixture, not a drifting lag.** A single-lag fit on B scatters 5° RMS. The per-sample age (where the posed θ crosses the reported yaw) is bimodal: ~75 ms or ~175 ms, exactly one 0.1 s republish period apart, 66–83 % of samples in the older mode per 10-minute window; A is unimodal at 94 ms. The bridge's 0.1 s timer republishes the latest heartbeat, so when it and the upstream 10 Hz stage tick nearly together a sample is fresh or one period stale. The investigation's "150 → 174 ms drifting" was this mixture read through a direction-split median. The lag fit for the heartbeat therefore lets each sample be one period older, whichever reads closer; a stamped source is fitted with one lag. Without this, every heartbeat calibration in a session like B would fail.
- **The parked pose is non-rigid in all three bags**, not only the 7-sweep bag: marker-pair separations at |y| < 1.5° are off the template by up to 1.3–1.4 mm (A, B) and 2.4 mm (7-sweep bag), against ≤ 0.29 mm (A, B) and ≤ 0.57 mm (7-sweep bag) at other yaws. So the position and the template residual are taken over the MOVING frames (frame time + lag inside a turning stretch), as the yaw is. Over all frames the template residual of the 7 sweeps was 0.76–1.28 mm; over the moving frames it is 0.20–0.47 mm.
- **The template residual is a pair-separation residual**, the largest mean (over the sweep) error of a marker-pair distance against the template. A marker that moved on BB changes its separations by up to its displacement; a per-marker mean residual vector instead picks up pose-dependent reconstruction error (0.5–0.8 mm per marker on the 7 sweeps).
- **Yaw samples are not interpolated across a lost track** (gap > 50 ms between posed frames): A's slews toward the reload pose lose the markers, and interpolating θ across those gaps produced 20° residuals.

**What was ruled out.** A 2D fit about world z (the first design): the 3D rigid fit needs no tilt estimate because the body frame carries the axis. An E-free estimator: within one bag it repeats about as well (SD 0.044° vs 0.031°, same yaw range in every sweep), but it reads −0.12° instead of +0.26° raw, so the offset would depend on the yaw range a window covers; A's slews (0–147°) and the sweeps (0–125°) cover different ranges. Applying E(y) to the aim: not done, moving and stationary relations differ by a few tenths.

**Accepted tradeoffs.** The template residual gate (0.5 mm) has thin margin on the 7-sweep bag (worst sweep 0.46 mm). The one-period-stale mixture would also absorb a genuine 100 ms lag jump within a sweep; it reports the stale fraction so that is visible. E(y) comes from one bag (the only one with sweeps).

## What changed

- **Estimator** (`bb_calibration.estimate_sweep_yaw_offset`):
  - `track_constellation` poses every frame against the 7-marker body template, label-free. The first frame, and any after a lost track or a 50 ms gap, is matched by geometry (`match_template`, with a 6 mm height tolerance for the tilted axis). Later frames reuse the previous pose to assign points within 3 mm. Each frame gets a 3D Kabsch fit. Frames with < 3 markers or RMS > 1.5 mm are rejected and counted.
  - `fit_yaw_latency` grid-fits the lag over −50…300 ms in 1 ms steps, with parabolic refinement. Samples are those with |dy/dt| > 5°/s, y inside E's valid range, and an unbroken track. The fit minimises the scatter of θ(t_y − τ) − y − E(y). The offset φ is the mean at the best τ. Its formal SE uses n_eff from the lag-1 autocorrelation.
  - Published offset = φ_raw − `raw_offset_at_pin_deg` + `pinned_yaw_offset_deg`.
  - Loud failures: `CONSTELLATION_TOO_FEW_FRAMES` (< 200), `CONSTELLATION_TOO_FEW_MARKERS`, `CONSTELLATION_RESIDUAL` (pair residual > 1.0 mm), `CONSTELLATION_TOO_FEW_MOVING`, `CONSTELLATION_LAG_AT_EDGE`, `CONSTELLATION_LAG_RESIDUAL` (> 1.0° RMS; a unit or source mismatch gives degrees).
  - The pause holds, visits and the 0.13° floor are deleted. So is the 2D-hold estimator.
- **Position.** `run_calibration` returns the body model's axis point as `bb_position_mm`; the arc fit's intersection is now `arc_position_mm`. It is the primary by the data: per-sweep SD x 0.04 / y 0.18 mm, against x 0.04 / y 0.38 mm for the arc fit. It also lands within 0.5 mm of A's and B's body-model points, while the arc fit sits 0.9–1.4 mm south of it in y. Tilt and all sweep gates are unchanged (arc fit).
- **Template** `resources/bb_marker_template.json`, schema 2 (the loader refuses schema 1):
  - **Markers:** all 7 yaw-stage markers in a body frame: origin on the yaw axis, z along the axis, x toward QTM 4.
  - **Build:** generalised Procrustes over yaw-balanced frames (≤ 40 per 2° bin per bag): A 2941, B 2950, and the 7-sweep bag 2520 with its parked frames excluded.
  - **Contents:** E(y), `gauge` (pin, raw value at the pin, uncertainty, the edit rule) and `sigma.repeatability_deg` 0.0308°, each with provenance.
- **σ** = √(formal SE² + 0.0308²): 0.046–0.070° per sweep.
- **Gate** (`check_calibration_consistency`, in `mocap_node`):
  - **Reference:** the state file (`~/bb_calibration_sessions/bb_calibration_last_accepted.json`), now storing position, lag, source and residual too. With no state file the calibration is accepted, persisted and logged at WARN; the template's pin is not a reference.
  - **Refusals:** `CALIBRATION_INCONSISTENT` (Δyaw > max(3σ, 0.15°) — both sweeps' σ combined since 2026-10-10 — or Δaxis > 1.5 mm in 3D), `TEMPLATE_RESIDUAL` (> 0.5 mm; `bb_moved` does not excuse it: a moved marker needs a new template), and `CALIBRATION_STATE_UNREADABLE` (a corrupt state file is no longer a silent fallback).
  - **Override:** `bb_moved` is one-shot, and is the flag for BB moved OR QTM recalibrated (rotating markers cannot tell the two apart). The accepted calibration becomes the reference.
- **`mocap_node` inputs:**
  - **Frames:** at their QTM stamp (`frame_ros_ns`, ROS clock), one per distinct stamp. The 200 Hz timer snapshots the latest frame, so duplicates are dropped; unstamped frames feed the arc fit only.
  - **Heartbeat yaw:** at ROS receive time; it was `time.monotonic()`, a different clock from the frame stamps.
  - **Stamped yaw:** the node subscribes to `bb/axis_estimates`. A `bb_yaw` joint (degrees; the sibling branch `bb-stamped-yaw-100hz`, BB fw 6 + can-bridge fw 28) is collected. With ≥ 100 samples in the window it is used with a single-age lag fit (expected a few ms); the two-joint message of older firmware falls back to the heartbeat.
- **Result message:** carries the estimator summary (frames, markers, residuals, source, lag, stale fraction, σ split), the arc-fit cross-check and the gate verdict. The INFO line reads `(lag N ms, gate ok)`. `ros_ws/docs/choreography.md` is regenerated for the new subscription.

## Validation (offline, node-shaped inputs, shipped template)

Inputs: labelled BB markers at their QTM stamps, labels dropped; the heartbeat at receive time; the CALIBRATING window; the whole `run_calibration` path. "old" is the anchor value the node published in the bag.

**Rosbag `2026-10-09_18-56-37`, 7 sweeps:**

| sweep | yaw offset ° (pinned) | σ ° | lag ms (stale %) | axis x, y mm (body model) | arc-fit x, y mm | template residual mm | lag-fit RMS ° | old anchor ° |
|---|---|---|---|---|---|---|---|---|
| 1 | 0.435 | 0.070 | 84.7 (0) | −975.86, −389.85 | −975.82, −391.22 | 0.46 | 0.28 | 1.020 |
| 2 | 0.493 | 0.050 | 83.8 (0) | −975.79, −389.87 | −975.79, −391.13 | 0.38 | 0.24 | 1.058 |
| 3 | 0.459 | 0.050 | 80.5 (3) | −975.78, −389.74 | −975.75, −391.03 | 0.37 | 0.24 | 1.018 |
| 4 | 0.443 | 0.046 | 80.5 (0) | −975.74, −389.51 | −975.72, −390.55 | 0.26 | 0.20 | 0.916 |
| 5 | 0.428 | 0.050 | 82.3 (0) | −975.75, −389.50 | −975.81, −390.40 | 0.33 | 0.22 | 0.820 |
| 6 | 0.447 | 0.046 | 82.6 (3) | −975.75, −389.48 | −975.75, −390.40 | 0.23 | 0.21 | 0.887 |
| 7 | 0.431 | 0.046 | 84.1 (0) | −975.75, −389.48 | −975.76, −390.41 | 0.20 | 0.20 | 0.878 |
| **SD** | **0.023** (mean 0.448, range 0.065) | | 1.7 | x 0.043, y 0.178 (z 1735.00 ± 0.04) | x 0.037, y 0.376 | | | 0.090 |

- 1087–1273 frames per sweep are posed (0–25 rejected) with 3–7 markers matched, and 32–38 heartbeat samples enter each fit.
- **Leave-sweeps-out (the check the investigation left undone).** Each sweep was estimated with E(y) refitted on the other six. The out-of-sample per-sweep SD is **0.031°** (range 0.090°), against 0.023° in-sample. The largest change of any sweep's value is 0.016°. The E coefficients move (e₁ 0.26–0.60), but the offsets barely do: E is constrained where the sweeps put their samples. The template's `repeatability_deg` is this 0.031°.
- E(y) as fitted (moving relation, at fixed offset): +0.03° at 10°, −0.11° at 50°, −0.31° at 70°, −0.57° at 90°, −1.10° at 125°.
  - The shape is like the investigation's (−0.44° at 70°, −1.57° at 125°). Its level differs because the template, the anchor direction and the lag model differ, and only differences of φ matter.

**Sessions A and B through the same estimator** (their bags start after their calibration, so these are the throw slews in 10-minute windows; per-window lag fitted):

| | windows: yaw offset ° (pinned) | lag ms | stale % | axis x, y mm | template residual mm |
|---|---|---|---|---|---|
| A (00:21) | 0.256, 0.191, 0.204, 0.194, 0.194 → **0.208** by construction (window SD 0.028, SE 0.012) | 94.2–97.1 | 3–4 | −976.22, −389.49 | 0.13–0.20 |
| A, last partial window | 0.050, **excluded**: template residual 0.64 mm > the gate's 0.5 mm, axis z +1 mm (unexplained) | 94.3 | 4 | | 0.64 |
| B (03:13) | 0.212, 0.197, 0.195 → **0.201** | 74.0–76.0 | 66–83 | −976.44, −389.89 | 0.16–0.18 |

- **B − A = −0.007°**, well within 0.05°. A and B are the same state, as both investigations found.
- **The 7-sweep bag reads 0.448°: +0.24° from A's frame.**
  - This is the shift the reinvestigation reported as +0.4 ± 0.2° (its methods spread +0.24…+0.6°, body model +0.43°). This estimator sits at the low end.
  - Marker geometry and the axis point are unchanged: body-model axis N vs A 0.47 mm.

**The pin and its uncertainty.** `gauge.raw_offset_at_pin_deg` = 0.0244° is A's mean raw value over its 5 accepted windows, so A reads exactly 0.208°. The transfer is good to the window SE (0.012°). Whether today's BB should aim with ~0.45° (this estimator's reading of the 18:56 state) or something nearer 0.6° is not decided by mocap: the cause of the A → 18:56 shift is unidentified. Take the pin as ± 0.2° until a validation sitting measures it. B's validation showed bearing error responds 1:1 to offset error.

## How to adjust the pin after the validation sitting

If ~40 validation throws give a mean bearing error implying an offset error δ (positive = the offset should be larger):
1. Edit ONLY `gauge.pinned_yaw_offset_deg` in `ros_ws/src/jugglebot/resources/bb_marker_template.json`, from `0.208` to `0.208 + δ`. Nothing else in the file changes; the template is not rebuilt.
2. Rebuild/deploy the package.
3. Set `bb_moved:=true` on `mocap_node` and calibrate once, so the stored reference moves by the same δ. Otherwise the gate compares a δ-shifted calibration with the old reference and refuses it when |δ| > the limit.

## Rule: moving BB or recalibrating QTM means re-pin + refit

The affine and the gauge are valid together for this mounting and QTM calibration only. After a physical move of BB or a QTM recalibration:
- set `bb_moved:=true`;
- calibrate (the gate lets one changed yaw/axis through and makes it the reference);
- refit `throw_affine_correction.json`, or re-pin from landings.

Recorded in the template's `gauge.rule`.

## Deferred

- **Merge into `skill-stack`, build, deploy, the first live sweep, and the validation sitting** that sets the pin. The node check is the INFO line `… (lag N ms, gate ok)`, the WARN for the first (reference-less) calibration, and the persisted state file.
  - *2026-10-10:* merged, built and deployed; live sweeps run since 2026-10-10 00:24, on the stamped `bb_yaw` since 13:45 (lag −0.2…+2.5 ms per sweep); the published offset is +0.776° after the owner's QTM world transform (base-frame path, [2026-10-10-bb-base-marker-frame](2026-10-10-bb-base-marker-frame.md)). **The pin sitting did not settle the pin:** `run_item2_sitting.sh` (2026-10-10 15:00 local, session `20261010T035151_835895Z`, 35 of 40 throws accepted) landed 117 ± 5 mm SHORT (radial, SD 31 mm) and +39.5 ± 2.5 mm lateral, and the rotation-vs-translation fit reads the lateral term as a translation (slope −0.3 ± 0.6°, intercept +46 ± 11 mm), not a frame rotation — so `settle_yaw_gauge.py`'s RE_PIN +2.406° is an artefact of its bearing rule and is NOT applied; the pin stays 0.208°. The same runner, plan, affine and signed s landed 21 mm RMS on 2026-10-09 (BB FW 5); since then BB FW 6 and bridge FW 28 were flashed, and in this sitting the hand jolted −3.3 → 0 mm before every throw (owner's observation; investigation under `~/bb_calibration_sessions/hand_jolt_20261010/`). Status stays in-progress until a sitting settles the pin (2026-10-11: settled, below).
  - *2026-10-11: Pin settled — 0.208° → 0.029°.* Two corrected sittings with the hand jolt of the 15:00 sitting fixed (BB FW 7 at 19:23, FW 8 at 23:34; BallButler logbook 2026-10-10-bb-hand-torque-ff-scale), both on the base-frame path, through BallButler `settle_yaw_gauge.py` (pre-registered: ≥ 30 accepted corrected throws; |mean bearing| ≤ 0.15° confirms, else add the mean bearing to the pin):

    | Sitting (local) | Session | Plan | Accepted | Node used | Mean bearing ± SE | Lateral ± SE | Rotation fit: slope / intercept | Verdict |
    |---|---|---|---|---|---|---|---|---|
    | 2026-10-10 19:23 | `20261010T082544_262394Z` | `local_validation_plan.json`, 40 throws | 28 of 40 | 0.790° | −0.278 ± 0.103° | −5.3 ± 2.1 mm | −0.15 ± 0.47° / −2.3 ± 9.7 mm | INCONCLUSIVE (28 < 30) |
    | 2026-10-10 23:34 | `20261010T123404_756897Z` | `local_validation_plan_range.json` (16 cells at 600/700 and 1450/1550 mm, bearings 10–38°, 48 throws) | 47 of 48 | 0.804° | **−0.179 ± 0.099°** | −4.2 ± 1.6 mm | −0.50 ± 0.21° / +5.0 ± 4.2 mm | **RE_PIN −0.179°** |
    | pooled (corroboration only) | both | | 75 | | −0.216 ± 0.073° | −4.6 ± 1.3 mm | −0.44 ± 0.19° / +3.7 ± 3.8 mm | (RE_PIN −0.216°) |

    **Decision:** the rule is applied per sitting with ≥ 30 throws, so the 23:34 sitting decides: `gauge.pinned_yaw_offset_deg` 0.208 → **0.029°** (exactly 0.208 − 0.179), recorded in the template's `gauge.repinned_on`; `raw_offset_at_pin_deg` and everything else unchanged. The pooled −0.216° lies 0.04° (0.4 SE) from the 23:34 value. The rotation fit's slope (−0.50 ± 0.21°) agrees with the −0.18° rotation within ~1.5σ; a residual range-dependent lateral term is not excluded and would belong to the affine, not the pin. In this sitting the landings were 24.6 mm RMS (criterion 26 mm; the report is INCONCLUSIVE on counts: 47 < 60, no core cells), mean (−8.1, −8.7) mm, mostly radial (−11.3 ± 2.7 mm short), which the pin does not move. **Replay (offline, the real `_finalize_calibration` on bag `2026-10-10_23-32-12`, temp state files; `~/bb_calibration_sessions/yaw_gauge_repin_20261010/`):** the sitting's calibration sweep reads +0.8045° under the old pin (= the live value) and **+0.6255°** under 0.029°; κ pooled from the live state file (26 records, all `pin_deg` 0.208) moves 179.495849° → 179.316849° (Δ −0.179000°, the same 2 outliers). `resources/bb_base_frame.json` keeps `pinned_yaw_offset_deg_at_build` 0.208: its records carry their pin. **Confirmation owed:** rebuild/deploy, then one sweep with the base markers seen (base_frame path; do NOT set `bb_moved` — the base gate compares like with like, and an armed `bb_moved` would stay armed). The node should report ≈ 0.62–0.63° (the base heading moves it: 0.6255° at the sitting's, 0.6207° at the 23:46 sweep's) with `gauge pinned 0.029°` in its launch line. A sweep on the sweep path (base unseen) before that would be gated against the 0.800° world reference and likely refused (Δ ≈ −0.18° > 3·√(σ² + σ_ref²) ≈ 0.11°).
    Status stays **in-progress** until that confirming sweep: the first live sweep and the validation sitting are done and the stamped path is resolved in its own entry, but the pin is not yet deployed.
- **The stamped `bb_yaw` path end to end** (sibling branch `bb-stamped-yaw-100hz`): the first live sweep with fw 6/28 should report lag a few ms with 0 % stale. *2026-10-11:* met and resolved in its own entry (BallButler 2026-10-09-bb-stamped-yaw-100hz): live sweeps on the stamped yaw since 2026-10-10 13:45, lag −0.2…+2.5 ms.
- The unexplained items: the A → 18:56 shift (+0.24° here), and A's last window (residual 0.64 mm, axis z +1 mm). Fixed base or room markers would separate a BB move from an encoder or frame change (REPORT Q3). *2026-10-11:* not blocking: the pin is now set by landings, and the base-marker frame (2026-10-10) separates a BB move from a QTM frame change from here on; the historical shift stays unexplained.
- Offline scripts in the worktree's `temp/bbyaw/sweep/` (`build1_template.py` … `build5_validate.py`, `probe_*.py`, not committed). They reuse the reinvestigation's `common.py` loader, GPA and axis helpers, and run the production functions.

## Verification

- Scoped, during the work (2026-10-09, `pytest tests/ros/test_bb_calibration_constellation.py tests/ros/test_mocap_node_yaw_gate.py tests/ros/test_perception_console_lines.py tests/ros/test_mocap_node.py tests/ros/test_bb_calibration_arc_span.py tests/ros/test_bb_calibration_coplanar.py tests/ros/test_bb_calibration_consensus.py ros_ws/src/jugglebot/jugglebot/tests/test_bb_calibration.py tests/ros/test_mocap_status.py tests/ros/test_choreography_map.py -q -p no:cacheprovider`): all green after the choreography regeneration.
- What the new and rewritten tests cover:
  - label-free matching and the tracker;
  - the lag fit on synthetic sweeps with known lags (20–250 ms);
  - the one-period-stale heartbeat (60 % stale: φ within 0.03°; a single-lag fit > 1° RMS);
  - the stamped 100 Hz path (4 ms lag, 0 % stale);
  - E held fixed (0–60° and 0–120° windows agree; without E they differ by > 0.1°), and E's valid range;
  - the gauge (an edit of the pin by δ shifts by δ) and σ;
  - every loud failure;
  - the gate: no reference, yaw, axis, residual even with `bb_moved`, the override, wrap;
  - `run_calibration` (position = body model, arc cross-check kept, missing anchor);
  - the `bb_yaw` JointState parsing (3-joint and 2-joint);
  - the shipped template and the loader's refusals;
  - in the node: first-calibration WARN, persistence, refusal, the one-shot reset of the reference, the corrupt state file, QTM-stamped frame de-duplication, and the stamped-source preference and fallback.
- The anchor-path tests (`test_bb_calibration_arc_span.py`, `_coplanar.py`, `_consensus.py`, `jugglebot/tests/test_bb_calibration.py`) are unchanged and run the legacy path.
- Full gate `./run_tests.sh --full`: the (date, command, result) triple is in the commit message (`git log --grep "Logbook-Entry: 2026-10-09-bb-constellation-yaw-offset"`).

**Re-pin merged and installed (skill-stack a5653e99, 2026-10-11 01:00–01:12):** full gate on the merged tree 6604 passed,
9 skipped, 1 xfailed, 2 failed — `test_skill_node.py::test_every_pattern_entry_opens_on_a_rest[columns_1ball-True]` and
`test_install_segment.py::test_TI1_seven_channel_frames_reach_the_wire_and_the_flags_fall`, both timing-sensitive, both pass
alone (another session's pytest run shared the box; the gate took 500 s against the usual 340); serial 6 passed. The merge
touches only the template, its two tests and these logbooks. The template's `how_to_adjust` now says: one sweep with the
base seen, no `bb_moved` (κ and the sweep move together); `bb_moved` once only on the sweep-only path. Awaiting the owner's
confirming sweep (≈ 0.62–0.63°) before this entry is resolved.

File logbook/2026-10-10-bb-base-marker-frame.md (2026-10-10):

---
title: BB base-marker frame — four fixed, unlabelled markers on BB's shelf are identified by geometry and posed every sitting; BB's pose in that frame (κ, p_b) is pooled over accepted sweeps, and `bb_pose_source` (sweep default | base_frame | auto) publishes the base pose composed with it, gated in the base frame so a QTM frame shift is reported and accepted while a BB move on the shelf is refused
type: feature
date: 2026-10-10
status: resolved
phase: "two-ball-skill-stack — R5 (Ball Butler calibration)"
related_plan: two-ball-skill-stack.md
files_changed:
  - ros_ws/src/jugglebot/jugglebot/bb_base_frame.py
  - ros_ws/src/jugglebot/jugglebot/mocap_node.py
  - ros_ws/src/jugglebot/resources/bb_base_frame.json
  - tools/bb_base_frame_build.py
  - tests/ros/test_bb_base_frame.py
  - tests/ros/test_mocap_node_base_frame.py
  - logbook/2026-10-10-bb-base-marker-frame.md
  - logbook/INDEX.md
subsystem:
  - tracking
  - ros
tags:
  - testing
---

# BB base-marker frame

## Problem

The sweep estimator measures BB in QTM's world frame. That frame moves 0.3–1.5 mm (non-rigidly) between sittings and is sometimes recalibrated, so a QTM change reads as a BB move: the gate refuses it, or `bb_moved` accepts it, and neither can tell "QTM moved" from "BB moved". BB is bolted to its shelf. The owner fastened four markers to the shelf (an L: C–S 115 mm; C–M–E collinear, 80 / 240 mm), with no QTM label. The first sitting that recorded them is bag `2026-10-10_12-26-22`: 10 sweeps, all accepted live.

## Analysis (bag 2026-10-10_12-26-22; scripts and their `.txt` outputs in `~/bb_calibration_sessions/base_frame_20261010/`; the full report was delivered in the session hand-off (the harness refused a REPORT.md))

- Identification: the four are the only 4-subset of the 13 unlabelled markers that matches the nominal distances within 4 mm. There were 0 ambiguous frames and 0 spurious triangles in 650 sampled frames. All four were visible together in 99.5 % of the distinct frames; the rest have no unlabelled markers at all.
- As-built vs nominal: CM +0.15, CE −0.18, CS +0.33, ME −0.33, MS +0.03, ES −0.13 mm. M sits 0.31 mm off the C–E line, and S is at 89.94° from it.
- The plane is tilted 1.04° from world z, toward the same azimuth as BB's yaw axis (0.8–1.0°). So the shelf, or QTM's z, is tilted, not BB on its mount.
- Base pose over the sitting: heading −179.051° with a per-frame SD of 0.004–0.005°. The SE of the static mean is 0.0003° (10 s blocks) and 0.0004–0.0009° per sweep window. The heading drifts −0.0014°/min (0.0036° over the 2 min); the origin's SD is 0.01–0.03 mm.
- BB-in-base over the 10 sweeps, using the live published values: κ = +179.491°, SD 0.050°, SE 0.016°; p_b = (177.54, 148.86, 76.71) mm, SD 0.03–0.04 mm. Offline replays give: stamped yaw κ +179.507° (SD 0.021°), heartbeat yaw at bag time +179.512° (SD 0.038°). The world-frame SD equals the BB-in-base SD to 0.0001°, because the base is static within a sitting.

## Discussion

- **κ comes from the live published offsets, not a replay.** Its gauge has to be the published one, the frame the deployed aim correction lives in. Offline, the heartbeat path can't reproduce the node's values: the bag has the recorder's receive times, not the node's. Per-sweep live−offline differences reach ±0.11° (SD ~0.07°), and the lag reads 72–76 ms offline vs 73–82 ms live. The stamped replay is reproducible and 2.4× tighter (SD 0.021°), but it is not what was published. The three seeds agree within 1.3 SE. Going forward the node pools whatever it accepts. Using `bb_yaw_source:=stamped` would shrink the pool's SD about 2.4×, but that is the owner's call (it is not changed here).
- **Sweep mode keeps the world gate unchanged.** The BB-in-base gate is the principled one, but making it the default would change the default behaviour. So under `sweep` the base frame is only a diagnostic and feeds the pool. A refused world-gate sweep whose BB-in-base is unchanged gets the suffix `· base frame: BB unmoved, QTM frame shifted`.
- **S is required for a pose.** C, M and E are collinear, so a match without S fixes no roll about their line. It also has no handedness: a mirrored L matches C–M–E with the normal up. The task's "≥ 3 of 4" therefore means S plus any two of C, M, E. S was visible whenever C, M and E were.
- **The pin is carried, not frozen.** Each κ record stores the marker template's `gauge.pinned_yaw_offset_deg` it was measured under. Pooling moves each record to the current pin. So the landing-derived delta from BallButler `settle_yaw_gauge.py` (which edits that pin) moves κ by the same delta, with no re-sweep and no edit to this resource. The pin's ±0.2° is common to every sitting and is reported, not folded into σ.
- **A separate module.** The base frame lives in `bb_base_frame.py`, beside `bb_calibration.py`, not inside it. It imports `kabsch` / `_assign` from there, and `bb_calibration.py` is unchanged.

## Change

- `bb_base_frame.py` (pure):
  - label-free identification (`identify_base_markers`): triangle proposals, Kabsch, normal up, non-collinear;
  - a tracker (`BaseFrameTracker` / `track_base_frame`), the GPA template (`learn_as_built`), and the static pose (`estimate_base_pose`: median-outlier rejection, block SE, visibility, template residual);
  - `bb_in_base` / `compose_bb_pose`, `pool_kappa` (wrap-safe, pin-normalised, SE floor), and `check_base_frame_consistency`;
  - `BaseFrameMonitor` (slow running estimate), the resource loader and the state file I/O.
- `mocap_node`:
  - collects every distinct frame's unlabelled markers in the window, and feeds the monitor at 5 Hz;
  - logs one INFO line when the base is first seen, with its shift vs the stored base pose;
  - new params `bb_pose_source` (default `sweep`), `bb_base_frame_file`, `bb_base_frame_state_file` (`~/bb_calibration_sessions/bb_base_frame_state.json`) and `bb_base_min_sweeps` (5);
  - under `base_frame`, publishes heading + κ_pool and o + R·p_b_pool with σ = √(SE_κ² + SE_h²), still reports the sweep's own value and the Δ, and pools each accepted sweep;
  - `auto` uses the base frame once the pool has ≥ 5 sweeps and the base is seen with residual ≤ 0.5 mm, else the sweep;
  - the world state file gains `pose_source`, `sweep_yaw_offset_deg`, `sweep_position_mm`, `base_frame` and `kappa_deg`.
- New refusal codes: `BASE_FRAME_NOT_SEEN`, `BASE_FRAME_MODEL_MISSING`, `BASE_FRAME_STATE_UNREADABLE`, `BB_IN_BASE_MOVED` (BB or the frame moved on the shelf; `bb_moved` starts a new pool), `BASE_FRAME_RESIDUAL` (frame knocked; `bb_moved` does not override), `BB_POSE_SOURCE_INVALID`. The existing codes are unchanged.
- `resources/bb_base_frame.json`: as-built template, the 10 seed records, `base_pose_at_build` (the first frame-shift reference) and the gauge note. It was built by `tools/bb_base_frame_build.py --bag …`; `--from-state` folds the node's pool back into the resource.

## Replay (10 sweeps)

**Leave-one-out.** The base path uses κ pooled over the other 9 sweeps. Live published values: Δ(base − sweep) RMS 0.053°, 9/10 within the sweep's 1σ, 10/10 within 2σ (sweep 6: Δ −0.093° against σ 0.069°). The base-path SD is 0.005° against 0.051° for the sweeps. The offline replays give the same 9/10 and 10/10, with RMS 0.040° (heartbeat) and 0.023° (stamped).

**Through the real `_finalize_calibration`** (ROS mocked, resource seed):
- `base_frame` publishes SD 0.002–0.004° against the sweeps' 0.021–0.038°;
- `auto` with an empty seed switches to the base frame after 5 pooled sweeps;
- `sweep` publishes the sweep exactly.

The literal ship criterion was "the base path within each sweep's σ for all 10". It is not met (9/10, as pre-registered), so **the default stays `sweep`**. The one miss is that sweep's own scatter.

## Verification

- Scoped (`~/Desktop/PDJ_venv/venv/bin/python -m pytest -q tests/ros/test_mocap_node.py tests/ros/test_mocap_node_yaw_gate.py tests/ros/test_mocap_node_keep_last_good.py tests/ros/test_perception_console_lines.py tests/ros/test_ball_butler_node.py tests/ros/test_choreography_map.py tests/ros/test_bb_calibration_*.py tests/ros/test_bb_base_frame.py tests/ros/test_mocap_node_base_frame.py tests/ros/test_qtm_clock_sync.py tests/ros/test_mocap_interface.py`, run 2026-10-10): **337 passed, 1 skipped**. That includes the 19 + 17 new tests.
- Full gate (`./run_tests.sh --full`, run 2026-10-10 13:01–13:12 local, this tree minus this line and the resource's provenance note): **PASS — 6485 passed, 9 skipped, 1 xfailed (parallel, 405 s) + 6 passed (serial, 26 s); total 431 s**. After those two edits: see the commit message.
- Not verified on hardware:
  - the node path live (the 5 Hz monitor's cost on the loaded Jetson; the first-sighting INFO line);
  - a second sitting. Whether κ holds across a QTM recalibration is THE open question: a non-rigid QTM warp that differs between BB and the base, ~180 mm apart, is not removed.

external_changes: none (BallButler not edited). `settle_yaw_gauge.py`'s ACTION line ("add δ to gauge.pinned_yaw_offset_deg … rebuild, re-run the sweep") stays correct. Under `base_frame` / `auto`, κ follows the pin after the rebuild, and the sweep is only needed to refresh the world reference.

**Merge follow-up (skill-stack, 2026-10-10):** `bb_yaw_source` default flipped `heartbeat` → `auto`. This sitting is the first clean-clock bag carrying both sources; the replay above reads 0.021° SD stamped against 0.038° heartbeat, meeting the rule pre-registered in 2026-10-10-bb-yaw-offset-spread-stamped-source (stamped SD ≤ 0.08° on a clean sitting). `test_auto_is_the_default_yaw_source_and_prefers_the_stamped_stream` pins it.

**Second sitting with the frame (2026-10-10 13:45 local, 8 sweeps, log `python3_1977193_1791600348251.log`):** all accepted on the stamped yaw (lag −0.2…+2.5 ms, clock gate 0.0 %, base markers 100 % visible); launch line `BB base frame seen … vs the stored base pose (build): 0.69 mm, +0.003° (QTM frame shift)`; per-sweep κ 179.467 179.514 179.505 179.574 179.518 179.502 179.531 179.513 → mean +179.515°, SD 0.030°, SE 0.011°; Δ vs the build's +179.491° ± 0.016° = +0.024° (1.3 combined SE, inside the 0.05° warp criterion); p_b (177.50, 148.99, 76.48) mm vs (177.54, 148.86, 76.71). Within the sitting the base pose crept +0.004° / 0.3 mm and the base residual 0.20 → 0.30 mm (watch). **`bb_pose_source` default flipped `sweep` → `auto`** on this evidence; `test_default_pose_source_is_auto_and_an_invalid_value_is_refused` pins it.

Operational notes: after the first sittings (14:10 / 14:13) the identifier searches every marker but BB's own (a QTM rigid body that labels a base marker blinded it there), a base expected but unseen leads the refusal instead of `bb_moved`, and κ is pooled robustly behind a 0.09° gate floor — see [2026-10-10-bb-base-frame-robustness](2026-10-10-bb-base-frame-robustness.md).

**Gauge re-pin (2026-10-11):** the template pin moved 0.208 → 0.029° from landings ([2026-10-09-bb-constellation-yaw-offset](2026-10-09-bb-constellation-yaw-offset.md), "Pin settled"), so κ now reads in the 0.029° pin: the live pool 179.4958° → 179.3168° (Δ −0.179000°, records keep `pin_deg` 0.208 and `pool_kappa` moves them); `bb_base_frame.json` keeps `pinned_yaw_offset_deg_at_build` 0.208.

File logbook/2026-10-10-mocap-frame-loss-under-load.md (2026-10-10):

---
title: mocap_node loses QTM frames when the Jetson is loaded — 180 unique frames/s on an idle box, 70–116 in the loaded sittings of 2026-10-10; the latest-snapshot publisher turns any stall into loss; the node's per-frame cost grew 22 % this week (secondary); fixes proposed, not built
type: investigation
date: 2026-10-10
status: open
phase: "two-ball-skill-stack — R5 (Ball Butler calibration) / catching"
related_plan: two-ball-skill-stack.md
files_changed:
  - logbook/2026-10-10-mocap-frame-loss-under-load.md
  - logbook/INDEX.md
subsystem:
  - tracking
  - ros
tags:
  - mocap
  - performance
---

# mocap_node frame loss under load

## Symptoms

The BB accuracy sitting of 2026-10-10 19:23 (session `20261010T082544_262394Z`, BB FW 7) had 12 of 40 landings
rejected by the extractor (3 "mocap source-stamp gap > 0.1 s", 9 "no ballistic track passed quality gates"), where
the 2026-10-09 FW 5 session rejected 0 of 110. The ball was visible in nearly every frame that existed; there were too
few frames. `/mocap_data` carried 180 distinct QTM frames/s on 2026-10-09 (the 200 Hz publish timer's ceiling against
a 300 Hz source) and 104–116 on every 2026-10-10 sitting from 12:26 on, 70 in the known-loaded 00:24 bag, with gaps up
to 157 ms. Catch-time SD (6.6 → 9.2 ms) and cross-range landing spread grew with it.

## Diagnosis (`~/bb_calibration_sessions/mocap_rate_20261010/REPORT.md`, scripts alongside; Opus agent, 2026-10-10)

- **The loss is real and happens inside the mocap_node process**, not in stamping or de-duplication:
  `/rigid_body_poses` (published per fresh packet, no stamps) matches the unique-stamp count within 0.3–1.3 % in every
  bag; the 200 Hz publish timer itself slowed (199.5 → 164–171 Hz) and stamp gaps > 20 ms contain a median of one
  publish where ~4 were due, so the receive thread and the timer stalled together. A QTM-side drop would have left the
  timer publishing duplicates. Every bag carries the same 4 bodies in the 6D stream, so re-enabling bodies in QTM did
  not change the packets.
- **Primary cause: CPU starvation by work outside the node.** 14:49 bag: 169 Hz for 10 s, then the drop; it stepped
  back to 171–173 Hz at 15:01:10, 90 s after the session, which is when this session's analysis agent finished its bag
  replays and scoped pytest run (its outputs are stamped 14:55, its idle wait began 15:00). 19:23 bag: already 147–162
  Hz before the session (another Claude session was working on the box), stepping down at session start and again 220
  s in, never recovering. 00:24 (a gate was running): 70 Hz. The onset lies between the 10:32 bag (~180 Hz) and 12:26
  (104 Hz), i.e. when the day's merges, gates and analyses began, not with any one code change: 12:26 ran the
  min-latency clock sync but not the base-frame code.
- **Secondary: the node's own per-frame cost grew 22 %** (34 → 41 % of one core, measured on recorded frames, 5
  interleaved repetitions, spread ≤ 2 %): the larger scene (14 → 19 markers) adds ~13 points (receive 609 → 699 µs
  per packet, publish 732 → 816 µs), the new code ~9 points (clock sync 9 → 41 µs per packet; base-frame candidate
  building ~95 µs per publish). The 5 Hz base-frame update averages 1.4 ms (max 6.7 ms) because tracking held in only
  63 % of updates and the full identification (0.8 / 3.6 / 4.6 ms at 13 / 19 / 27 candidates) ran often. ~80 % of
  the per-packet cost is building Python ROS messages (`on_packet` builds 4 `PoseStamped` per 300 Hz packet). HEAD
  sustains 171.5 Hz on an idle box (the 14:49 tail), so this is fragility, not the loss itself.
- **Amplifier: the latest-snapshot design.** QTM arrives over TCP with every frame; `on_packet` keeps only the latest
  snapshot and the 5 ms timer publishes it, so packets arriving in a burst after a stall overwrite each other: delay
  becomes loss. Nothing grows over time; buffers are bounded.
- The "receive latency 1.9 → 8.9 ms" figure is mostly a change of definition with the min-latency sync (excess over
  the fastest packets instead of a mean): compare only bags from 12:26 on (4.5 ms clean, 9–13 ms loaded).
- Side finding, not chased: stamps go backwards 164–490 times per bag, including the healthy 10-09 session; the
  publisher may read markers and the frame timestamp under separate lock acquisitions.

## Discussion

The rule "no test suites or heavy jobs during a sitting" (logbook `2026-10-10-mocap-min-latency-clock-sync`) was
written for the clock sync; it also governs frame supply, which the catch prediction and the landing extractor both
live on. The node runs with no priority or core reservation and ~40 % of a core of Python per frame on a shared box.

## Proposed fixes (not implemented; pointers in the report)

1. Queue every frame in a bounded deque in `mocap_interface.on_packet` (`mocap_interface.py:471-480`) and have
   `_publish_mocap_data` (`mocap_node.py:606-660`) publish each with its own stamp, so delay becomes latency, not
   loss, and the 180 Hz ceiling goes.
2. Priority / core for mocap_node (`launch/jugglebot_launch.py:363`); keep tests, builds and replays off the box
   while the stack is up.
3. Cut per-packet cost: build `PoseStamped` only when publishing (`mocap_interface.py:407-436`), `math.isnan`
   instead of numpy per marker (:381, :468), precomputed index→name lookup (:673).
4. Log QTM's own drop counter (parsed, unused, :384-386) and frame-number gaps in the 1 Hz debug line.
5. Base identification at ≤ 1 Hz once tracked, or vectorised (`bb_base_frame.py:221-258`); find out why tracking
   fails 37 % of updates.
6. Live check for the next sitting: `pidstat -u -t -p $(pgrep -f lib/jugglebot/mocap_node) 1` and `mpstat -P ALL 1`
   into files; node threads well under 100 % with total CPU high = load; threads at ~100 % = the node's own cost.

## Open

- **Fix 1, 3 and 4 built 2026-10-10** (bounded frame queue, cheaper per-frame work, loss counters + WARN): logbook
  `2026-10-10-mocap-frame-queue`, branch `mocap-frame-queue-2026-10-10`, not merged or deployed; this entry stays open
  until `/mocap_data` is verified at ~300 unique frames/s live.

- n = 1 bag per condition around the onset; the load at 12:26 and 19:23 is inferred (no CPU log).
- Decide whether to build fixes 1–4 before relying on catches (two-ball juggling).

- 2026-10-11: the queue's first sitting shows ~0.4 % sporadic single-frame QTM skips (QTM-side, not node loss) - see `2026-10-10-mocap-frame-queue`, "First sitting on the queue".

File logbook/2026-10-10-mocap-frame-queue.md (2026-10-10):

---
title: mocap_node publishes every QTM frame from a bounded queue (150 frames, 0.5 s) instead of a latest-frame snapshot; per-frame work cut so all ~300 frames/s cost 23-24 % of a core against 43 % for 200 before; frame loss now logged (1 Hz counters, throttled WARN); built and gated, not deployed
type: bugfix
date: 2026-10-10
status: in-progress
phase: "two-ball-skill-stack — R5 (Ball Butler calibration) / catching"
related_plan: two-ball-skill-stack.md
files_changed:
  - ros_ws/src/jugglebot/jugglebot/mocap_interface.py
  - ros_ws/src/jugglebot/jugglebot/mocap_node.py
  - tests/ros/test_mocap_frame_queue.py
  - tests/ros/test_mocap_interface.py
  - tests/ros/test_mocap_node.py
  - tests/ros/test_mocap_node_base_frame.py
  - tests/ros/conftest.py
  - logbook/2026-10-10-mocap-frame-queue.md
  - logbook/2026-10-10-mocap-frame-loss-under-load.md
  - logbook/INDEX.md
subsystem:
  - tracking
  - ros
tags:
  - mocap
  - performance
---

# mocap_node: a bounded frame queue instead of the latest-frame snapshot

## Problem

From the investigation `2026-10-10-mocap-frame-loss-under-load`: QTM streams every frame at 300 Hz over TCP.
`MocapInterface.on_packet` overwrote one latest-frame snapshot, and a 5 ms timer in `mocap_node` published it.
When the process was CPU-starved, the receive thread and the timer stalled together. The packets that then arrived
back to back overwrote each other, so a delay became a loss. The result was 180 unique frames/s on an idle box and
70-116 under load, with gaps up to 157 ms. The node spent about 41 % of a core per second, about 80 % of it building
Python ROS messages. QTM's drop counter was parsed but never used, so the loss never showed in any log.

## Change

- **Queue (`mocap_interface.py`).**
  - `on_packet` builds one `MocapFrame` namedtuple per QTM frame and appends it to
    `collections.deque(maxlen=FRAME_QUEUE_MAXLEN)`, all under one `data_lock`. The tuple holds: frame number, QTM µs,
    the ROS stamp, the ROS receive time, aligned, labelled `[(label, x, y, z, r)]`, unlabelled `[(x, y, z, r)]`,
    bodies `(name, frame_id, x, y, z, qx, qy, qz, qw)` and the 7 BB rows.
  - The ROS stamp is converted once, at receive, in `_update_qtm_clock_sync`, which now returns
    `(receive_ns, stamp_ns)` from the same min-latency sync.
  - `maxlen` is 150, which is 0.5 s at 300 Hz. That is about 3× the longest gap in the loaded sittings (157 ms).
    Only a stall longer than 0.5 s loses frames: the oldest go first and are counted as `overflow_drops`. The same
    bound caps the latency a starved node can build up at 0.5 s.
  - A packet that repeats the last frame number is not queued (counted as a duplicate). A jump forward is counted as
    QTM gap frames. A frame number that goes backwards is counted as a QTM restart, not a gap. A disconnect clears the
    queue and the counter.
  - `drain_frames()` / `latest_frame()` / `take_stream_stats()` replace the snapshot getters and `clear_*`. These
    are removed: `get_all_markers_base_frame`, `get_labelled_markers`, `get_body_poses`, `clear_markers`,
    `clear_body_poses`. `latest_frame_ros_ns()` stays, reading the last record. `ball_butler_markers` (used by
    mocap/status) is still the latest frame's.
- **Publisher (`mocap_node.py`).**
  - Each tick of the unchanged 5 ms timer drains the queue and publishes **every** frame, oldest first, through
    `_publish_frame`: `/mocap_data`, `/rigid_body_poses` (for frames that carry bodies) and `/bb/markers`, each with
    the frame's own stamp. It also feeds the base frame and the calibration window.
  - Message types, topics and stamp semantics are unchanged. For rigid bodies, the header is stamped at publish time
    and each pose at its frame's receive time, as before.
  - An empty tick now publishes nothing. Before, it re-published the last frame with no markers: about a third of
    `/mocap_data` in the loaded bags.
  - The tick stays at `hw.TRACKING_MOCAP_DT_S` = 5 ms. A drain-all tick only sets latency (0-5 ms; consumers fit
    against the QTM stamps). A faster tick would cost executor wake-ups to save at most 2.5 ms of mean latency, and
    that constant lives in a gated file anyway.
- **Cheaper per-frame work.** I measured each change and took the hot spots from the profile:
  - `PoseStamped` is built only when publishing, once per body per frame. The receive path keeps tuples.
  - `RigidBodyPose`'s default `PoseStamped` is filled in place instead of building a second one; that alone was about
    1/5 of the publish time.
  - `math.isnan` replaces numpy per marker.
  - Index→name lists are rebuilt only when `marker_dict`/`body_dict` is replaced (this was an O(L²) scan per packet).
  - The quaternion is computed with plain floats (`quaternion_from_rotation_list`, pinned branch for branch against
    the old numpy version).
  - The alignment check uses `math`.
  - The base-candidate array is built only when `_feed_base_frame` will use it (`_base_feed_due`: every frame of a
    calibration window, otherwise once per 0.2 s of frame time).
  - Markers are built by `_marker_fast`, which writes rosidl's `_x`/`_position`… slots directly. It is enabled only
    if both classes have exactly that slot layout and an import-time self-check builds a message equal to the
    checked builder's; otherwise the old setter path (`_marker_checked`) is used. The checked path is what runs
    under the tests' message stand-ins.
- **Loss visibility.**
  - `_check_stream_health` runs on the 1 Hz clock-offset timer. It appends to the existing
    `qtm clock sync: …` DEBUG line: `stream N frames/s, queue max d/150, lost: node overflow x (total X), QTM gaps
    y frames (total Y), duplicates, QTM restarts, QTM 2D drop ‰, out of sync ‰`. The ‰ figures are QTM's 3D-header
    2D drop and out-of-sync rates, the highest since the last line.
  - On any overflow or QTM gap it logs one WARN: `mocap: N QTM frames lost in the last T s — a dropped by
    mocap_node (frame queue full …), b never received from QTM (k frame-number gaps); QTM 2D drop …‰ — check the
    Jetson load …`. The WARN is limited to one per `MOCAP_LOSS_WARN_PERIOD_S` = 10 s; losses inside that window are
    summed into the next WARN, so none goes unreported.
- **Side finding fixed: stamps going backwards.** In the 10-09 and 10-10 bag stats, **every** backward step
  (164-490 per bag, 0.2-21 µs) is an empty message right after a real one. The old empty tick re-published the
  previous frame's QTM time through an offset that had moved down a few µs. With one conversion per frame and no
  re-publishing, this cannot happen any more. A clock-sync re-anchor larger than one frame period can still step the
  stamps back; that comes from the sync, not the queue.

## Verification

Benchmark: `~/bb_calibration_sessions/mocap_queue_20261010/` (`bench2.py`, `run_bench2.sh`, `bench2_summary.txt`).
It is the investigation's `bench.py` adapted:
- the same 3000 recorded frames per dataset, rebuilt into real QTM packets and parsed by `qtm_rt`;
- the real `on_packet` / `_publish_mocap_data`, with the real Foxy message classes and `serialize_message` standing
  in for publish;
- a tick after 2 of every 3 packets (200 ticks/s against 300 packets/s);
- 5 interleaved repetitions of old (`590a1d13`), new and new with the checked builder, under `nice -n 10`;
- run 2026-10-10 22:13-22:22 with other work on the box (load average 2-4).

| µs, mean ± SD over 5 reps | old FW5 | new FW5 | old 19:23 | new 19:23 | old 14:13 | new 14:13 |
|---|---|---|---|---|---|---|
| receive per packet (parse + `on_packet` incl. sync) | 676 ± 9 | 173 ± 2 | 795 ± 58 | 200 ± 9 | 802 ± 16 | 204 ± 13 |
| publish per published frame | 776 ± 11 | 515 ± 3 | 938 ± 93 | 575 ± 21 | 946 ± 12 | 592 ± 39 |
| frames published per 300 packets | 200 | 300 | 200 | 300 | 200 | 300 |
| CPU per s at 300 packets/s | 358 ms (36 %) | 206 ms (21 %) | 426 ms (43 %) | 233 ms (23 %) | 430 ms (43 %) | 239 ms (24 %) |
| new/old CPU, paired by rep | | 0.576 ± 0.004 | | 0.547 ± 0.024 | | 0.555 ± 0.032 |

- The new code publishes **every** frame (300/s, against at most 200 of which about 180 were unique) at 55-58 % of the
  old CPU.
- The checked-setter variant costs 25 / 29 / 30 % of a core. The slot-writing builder saves about 5-6 points and
  builds messages field-identical to the checked builder on all 1000 frames checked per dataset (also after a
  serialize/deserialize round trip).
- The old 19:23 figure (43 %) reproduces the investigation's 41 %, which is within this run's load.
- **Equivalence** (`lockstep_compare.sh`, one tick after every packet, old against new, 3000 frames × 3 datasets):
  every `/mocap_data`, `/bb/markers` and `/rigid_body_poses` message is field-identical after deserialization,
  including stamps, labels, NaN BB rows and quaternions. The raw CDR bytes differ only in uninitialised padding.
- **Tests** (`tests/ros/test_mocap_frame_queue.py`, 21 new tests):
  - A 45-frame stall followed by one tick publishes 45 messages per topic, with strictly increasing, distinct stamps
    equal to each frame's own conversion, and each message carries its own frame's markers.
  - Overflow drops the oldest and is counted.
  - An empty tick publishes nothing.
  - Duplicates, gaps and QTM restarts are counted correctly, and a disconnect clears the queue.
  - Stamps never go backwards under a moving offset with jittered latency.
  - Name lookups follow a replaced dict; bodies carry the right frames and offset; rigid-body stamps and values are
    right.
  - The calibration collector still takes each frame once (per distinct stamp).
  - The base monitor still runs 5 times per second of frame time, and candidates are built only then.
  - The 1 Hz line carries the counters; the WARN fires at once, is throttled, sums the counts and stays quiet with no
    loss.
  - The float quaternion matches numpy on every branch, NaN included.
  - The fast-builder self-check accepts rosidl-style classes and rejects others.

  Existing tests moved to the frame API: `test_mocap_interface.py`, `test_mocap_node.py`,
  `test_mocap_node_base_frame.py`. The conftest `RigidBodyPose` stand-in now default-constructs a full
  `PoseStamped`, as the real message does.
- 2026-10-10, scoped: every `tests/ros/test_*.py` that imports mocap_interface/mocap_node, plus the three logbook
  tests. Result: 961 passed, 1 skipped.
- 2026-10-10, full gate (`./run_tests.sh --full` from the worktree): see the commit's `Tests:` line.

## Not verified live

- `/mocap_data` unique frames/s on an idle box: expect about 300, up from 180. Also check `/rigid_body_poses` and
  `/bb/markers` at the same rate.
- The 1 Hz `qtm clock sync: … stream …` DEBUG line in a real log (rosout/bag), and QTM's real drop / out-of-sync
  figures.
- The WARN under a deliberate load: for example, a scoped pytest during an idle stack. Expect no loss for stalls
  under 0.5 s and the queue high-water mark to rise in the DEBUG line. Only a starvation longer than 0.5 s should
  warn "dropped by mocap_node".
- Real `publish` cost with DDS and subscribers at 300 Hz (the benchmark used `serialize_message`), and the executor
  cost of a catch-up tick. After a 150 ms stall one tick publishes about 45 frames, roughly 25 ms, and delays the other
  callbacks in the node (heartbeat, `bb/axis_estimates`) by that much.
- Downstream at 300 Hz:
  - The ball tracker's frame-count thresholds (`missed_frames_to_lose` = 10, `TRACKING_MAX_FRAMES_WITHOUT_MEASUREMENT`
    = 200) now mean 33 ms / 0.67 s of frames, against about 50 ms / 1 s of messages before (which included empty
    re-publishes).
  - skill_node's frame check now gets about 300 Platform samples/s (deque maxlen 400 still covers its 1 s window).
  - Bags get 1.5× the `/mocap_data`, `/rigid_body_poses` and `/bb/markers` messages.
  - A BB calibration window collects about 300 frames/s, without the duplicate snapshots that went into the arc fit
    before.

## Follow-ups (out of scope)

- Priority or core pinning for mocap_node in the launch file.
- Base-frame identification rate / vectorising `identify_base_markers` (4-7 ms GIL pieces).
- The `PoseStamped` header of each rigid body still carries the receive time, not the QTM-derived frame stamp.
  Switching it would give `/rigid_body_poses` consumers a capture-time stamp (no node reads it; check the offline probes under `tools/probes/` before changing it).

**Reviewer's adjustment (merge, 2026-10-10 23:05):** `ball_tracker_node.py` `missed_frames_to_lose` 10 → 15 so the
lose-track window stays ~50 ms at ~300 msgs/s (it would have shrunk to ~33 ms). `TRACKING_MAX_FRAMES_WITHOUT_MEASUREMENT`
= 200 stays (gated `hardware_config.py`; now ~0.67 s of coasting instead of ~1 s) — revisit at the next admissible re-sweep.

**Merged-state gate (skill-stack 7500b425, 2026-10-10 22:38–22:44, alone on the box, log
`temp/logs/full_gate_mocap_queue_merged_20261010.log`):** PASS — 6596 passed, 9 skipped, 1 xfailed; serial 6 passed.
Installed with `colcon build --packages-select jugglebot` at 22:46; live verification (≈300 unique frames/s on `/mocap_data`
on an idle box, the 1 Hz stream line, a loss WARN only under real starvation) is the owner's next launch.

## First sitting on the queue (2026-10-10 23:32-23:44; WARN tuned 2026-10-11)

Bag `~/Desktop/rosbags/2026-10-10_23-32-12`, session `~/bb_calibration_sessions/20261010T123404_756897Z/` (analysis
scripts and `REPORT.md` in `~/bb_calibration_sessions/qtm_gaps_20261010/`).

Measured: `ros2 topic hz /mocap_data` ~300 Hz, 47 of 48 landings accepted. The session bag holds 168,378 `/mocap_data`
messages over 564 s (298.75 Hz mean); every stamp step is an exact multiple of 3.333 ms (residual std 0.001 ms).
679 gap events, 710 missing frames = 0.42 % of expected: 648 single-frame, 31 two-frame, none longer. Mean 11.9 gap
events per 10 s (min 4, max 24). No periodicity (phase mod 0.5/1/2 s and frame index mod 2..300 flat), Poisson-like
but mildly clustered (39 % of gaps within 100 ms of another); rate during throws 1.30/s vs 1.14/s outside, so not
throw-correlated. The node's own counter agrees with the bag: 718 gap frames in the 1 Hz lines vs 709 from stamp
slots, so the frame number and the QTM timestamp skip together (a true missing slot, not a renumbering). The message
before a gap arrived late (54 % vs 17 % baseline had a > 6 ms receive interval), the gap itself is not tied to a large
publish batch. The WARN's repeated 8-24 frames per 10 s were all of this kind; the 21 s window at launch (3219 frames
dropped by the node, queue full) was the startup stall, the only node-side loss. QTM's out-of-sync figure read 2-7 ‰
in the DEBUG lines while 2D drop read 0 ‰.

Receive path read, not changed: qtm_rt's `Receiver` loops over every complete RT packet in the TCP buffer and calls
`on_packet` once per data packet, so two packets in a read are not collapsed; the node's accounting counts
`frame_number > last + 1` and treats a lower number as a restart, a duplicate returns before the count. No
off-by-one found. Inference: QTM did not send these frames (or a TCP stall upstream of the Jetson ate them); a
FW 5 bag (2026-10-09, 180 distinct frames/s via the 200 Hz timer) cannot say whether it is new.

Changed: the loss WARN now judges each 10 s window and fires only when MORE than 5 % of the expected frames
(received + never sent) were lost, node overflow and QTM gaps combined (owner's rule). Below that, the counts stay in
the 1 Hz DEBUG stream line. The text names the side: node overflow says the Jetson was starved (check its load);
frames never received from QTM say to check QTM's real-time output; the Jetson-load advice no longer appears when the
node dropped nothing. Tests: `tests/ros/test_mocap_frame_queue.py` (4 % silent, 6 % warns, overflow-only warns with
the starvation wording, a 200-frame outage warns once).

Status stays in-progress until the owner confirms the WARN behaviour on a sitting.

**Merged-state gate for the WARN rule (skill-stack f5221120, 2026-10-11 00:12–00:19, log
`temp/logs/full_gate_gapwarn_merged_20261011.log`):** 6605 passed, 9 skipped, 1 xfailed, 1 failed —
`tests/ros/test_skill_node.py::test_columns_releases_each_correlate_to_their_own_track`, no mocap involvement, passed
alone at 00:20 (another agent's scoped test run shared the box during the gate); serial 6 passed. Installed 00:21.

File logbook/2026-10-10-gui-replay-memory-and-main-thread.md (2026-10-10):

---
title: GUI replay - memory and main-thread cost (session buffer removed, typed per-leaf slots, derive-once charts)
type: bugfix
date: 2026-10-10
status: resolved
phase: "gui-rosbag-replay - Phase 4 follow-up (memory)"
related_plan: gui-rosbag-replay.md
files_changed:
  - logbook/2026-10-10-gui-replay-memory-and-main-thread.md
  - logbook/INDEX.md
  - plans/active/gui-rosbag-replay.md
  - ros_ws/gui/css/replay.css
  - ros_ws/gui/js/catching-cone-model.js
  - ros_ws/gui/js/replay/cache.js
  - ros_ws/gui/js/replay/chart-store.js
  - ros_ws/gui/js/replay/chunk.js
  - ros_ws/gui/js/replay/digest.js
  - ros_ws/gui/js/replay/engine.js
  - ros_ws/gui/js/replay/mcap-decode.js
  - ros_ws/gui/js/replay/mcap-worker.js
  - ros_ws/gui/js/replay/mode.js
  - ros_ws/gui/js/replay/session.js
  - ros_ws/gui/js/replay/sources.js
  - ros_ws/gui/js/replay/ui/absent.js
  - ros_ws/gui/js/replay/ui/format.js
  - ros_ws/gui/js/replay/ui/index.js
  - ros_ws/gui/js/replay/ui/lobby.js
  - ros_ws/gui/js/replay/ui/picker.js
  - ros_ws/gui/js/replay/wiring.js
  - ros_ws/gui/js/ros-bridge.js
  - ros_ws/gui/test_robot_models.html
  - tests/ros/js/mcap_oracle_harness.js
  - tests/ros/js/mcap_worker_transfer_harness.js
  - tests/ros/js/replay_cache_harness.js
  - tests/ros/js/replay_chart_harness.js
  - tests/ros/js/replay_digest_harness.js
  - tests/ros/js/replay_feed_harness.js
  - tests/ros/js/replay_mcap_source_harness.js
  - tests/ros/js/replay_mode_harness.js
  - tests/ros/js/replay_test_support.js
  - tests/ros/js/replay_typed_columns_harness.js
  - tests/ros/js/replay_ui_absent_harness.js
  - tests/ros/js/replay_ui_lobby_harness.js
  - tests/ros/test_gui_replay_bridge.py
  - tests/ros/test_gui_replay_cache.py
  - tests/ros/test_gui_replay_chart.py
  - tests/ros/test_gui_replay_digest.py
  - tests/ros/test_gui_replay_feed.py
  - tests/ros/test_gui_replay_mcap_source.py
  - tests/ros/test_gui_replay_memory_contract.py
  - tests/ros/test_gui_replay_mode.py
  - tests/ros/test_gui_replay_ui_absent.py
  - tests/ros/test_gui_replay_ui_lobby.py
  - tests/ros/test_replay_mcap_oracle.py
  - tests/ros/test_replay_typed_columns.py
subsystem:
  - gui
tags:
  - performance
  - testing
  - docs
---

# GUI replay: memory and main-thread cost

## Summary

Owner, 2026-10-10 evening: Win10 Chrome 154, tab at 3 GB, "Aw, Snap! Out of Memory" after panning and zooming a ~7 min recording, with lag and slow buffering. Three units landed. M1 deleted the live session buffer end to end and halved the residency (8 slots, 10 s ahead). M2a typed the slot records per leaf and transferred them instead of cloning. M2b made the chart store derive once per chunk from the typed columns and coalesced resident changes to one chart rebuild per animation frame. The first hypothesis (the session buffer at about 1 MB per recorded second dominates) was reframed by measurement; see Discussion. Software complete; the owner's Win10 run is unverified.

## Symptom

Pan/zoom on a ~7 min recording, 3 GB tab, OOM crash. Before the crash: lag, slow buffering, long main-thread stalls.

## Hypothesis

The orchestrator's first reading: the live session buffer (the 600 s ring built at message arrival in `ros-bridge.js`) costs about 1 MB per recorded second and dominates; a scalar-typed slot layout would then fix the replay slots.

## Measurement

Headless Chromium on the Jetson (heap after forced GC unless noted), scripts in the session scratchpad. Bags: `2026-10-02_12-43-28` (busy, 109 slots, ~7 300 msg per 10 s slot), `2026-06-17_15-13-42` (7 min, the owner's case), `2026-06-23_20-31-20` (the 13 h bag: low traffic, so a poor case for memory; used only for the ring-fill smoke).

| Quantity | Measured |
|---|---|
| Live session buffer, record path (120 s, 87 620 msgs) | +8.21 MB, i.e. 41 MB projected at 600 s, about 94 B per message; hydrate garbage about 1.5 kB per message (about 1.1 MB/s) |
| Live idle heap, 60 s | 6.0 MB |
| Replay slot, busy bag, decode + structuredClone | 16.5-17.9 MB per slot (about 1.7 MB per recorded second: the "1 MB/s" figure was this hydrated replay-slot shape, not the session buffer) |
| Scalar-only typed layout (variant A/B) | 16.7 of 17.0 MB (2 % saved) |
| Per-leaf CSR typing of arrays of objects (variant C) | 5.4 of 17.0 MB (68 % saved) |
| Main thread per slot arrival (clone + derive twice + nine chart rebuilds) | about 600 ms vs 14 ms worker decode work |
| 7 min bag, 90 s seek storm | floor 52.9 MB (peaks 63.4), 287 long tasks, 93.7 s total, worst 839 ms |

## Discussion

The reframing. The session buffer is 41 MB per 600 s plus about 1.1 MB/s of garbage, not a gigabyte. The "about 1 MB per recorded second" the owner and orchestrator had in mind was the cost of a hydrated replay slot. A scalar-only typed layout saves 2 %, because the slot cost is arrays of OBJECTS (`/balls`, `/rigid_body_poses`, `/mocap_data` bodies), not scalar columns: each element is a heap object with its own fields. Per-leaf CSR typing (an `offsets` Uint32Array plus one typed column per leaf) removes the objects and saves 68 %. Had we shipped the scalar layout first we would have spent a unit for 2 %.

Bytes were not the whole story. The lag is main-thread work per slot arrival: the structured clone of a 17 MB heap graph, deriving the chart signals twice (once for the resident store, once for the digest), and nine chart rebuilds, about 600 ms against a 14 ms worker decode. So transfer (typed buffers detach, no clone), derive-once (one per-chunk cache shared by `setResident` and the digest) and one `setData` per animation frame matter as much as the bytes. Crash risk and stalls share one cause (per-row object churn), which is why one typed shape fixes both.

Why the session buffer was dropped although it was cheap (41 MB). Low value: the newest recording covers "replay the last session". It added churn on every live message (the tap, hydrate garbage), and removing it removes a second feed source, one code path fewer in `mode.js`, `wiring.js` and the lobby. Cost of removal: the last few seconds before a live disconnect are not replayable until the bag closes. Accepted.

Residency cut. `maxResident` 16 to 8 and `aheadSec` 20 to 10: with the slot at 5.6 MB the worst-case resident set is about 45 MB, and the prefetch only needs to cover one decode latency (about 340 ms including HTTP) at the speeds offered. Cache expectations were re-derived rather than loosened.

Not done, and why. Charts at 20 Hz: the digest and the two-tier store already bound the draw cost and the owner's complaint was not chart rate. A worker-side digest: it would move the by-product digest off the main thread but needs the derivation code in the worker (a second copy to keep in sync); after derive-once the digest is a by-product of work already done, so it was deferred. The 3 GB crash itself was never reproduced headless: the busy-bag floor was 70 MB before, so the owner's 3 GB must involve Win10 Chrome allocator or GPU behaviour we cannot see here; the change removes the largest per-row churn but cannot prove the crash gone.

## Fix

M1 (session buffer removed, residency, cone): deleted `js/replay/session.js`; in `sources.js` removed `SessionBufferSource`/`createSessionBuffer`/`SESSION_BUFFER_SEC` (only `McapSource` exported); removed the `getSessionBuffer` tap in `ros-bridge.js`, the `{kind:'session'}` branch and the 'no session buffer' refusal in `mode.js`/`wiring.js`, the "Replay last session" button (`ui/lobby.js`), the picker session row and `sessionInfo` (`ui/picker.js`), the 'memory' state cell and session `buildRows` argument (`ui/format.js`), `ui/index.js` and `ui/absent.js` session branches, a css rule; `cache.js` `maxResident` 8, `aheadSec` 10. Peer hand-off: `js/catching-cone-model.js` staleness now on `clock.now()` (virtual, frozen while paused), marker dropped; `test_robot_models.html` call sites updated.

M2a (typed slots): `mcap-decode.js` `decodeSlot` returns `{type, n, t, cols, kinds}` (scalars Float64Array, bools Uint8Array, strings plain, arrays of objects CSR with dotted leaf names, arrays of primitives CSR with one `flat`, irregular as 'any' and cloned); `mcap-worker.js` transfers every typed buffer (deduped); `chunk.js` `makeTypedHydrator`/`isTyped`, `makeTopic`, `chunkFromRecord` adopts without copy.

M2b (readers): `chunk.js` gains `buildColumn(s)` (moved from `mcap-decode.js`, re-exported), `typedColumns(topic)` (memoised), `leafFiller`; `chart-store.js` `derive()` reads `motor_states` CSR leaves into preallocated per-axis Float64Arrays, `latestBefore` returns `{t, tp, k}`, `derivedFor` is the one per-chunk cache; `mode.js` coalesces `syncResident` to one `store.setResident` per animation frame (flushed at entry, cancelled at exit); `engine.js` `dataOf` reads the raw column (fixes a latent true/false vs 1/0 mismatch in the on-change gate); `digest.js` comments.

## Verification

- 2026-10-10, M1, `pytest tests/ros -k 'gui or replay' -q`: 442 passed, 1 skipped. Record path cost 0 (was 8.21 MB per 120 s); live idle heap 6.0 MB before and after. New `tests/ros/test_gui_replay_memory_contract.py` (no tap, no session symbol in js, cone uses clock) and lobby `test_no_session_button_or_row`.
- 2026-10-10, M2a, same scoped command: 448 passed, 1 skipped. Oracle: 4 slots, 446 741 values, 0 mismatches (hydrate every row, re-flatten by value; null == NaN/Inf). New `test_replay_typed_columns.py` (6 tests, including transfer detach and the real worker transferring every buffer).
- 2026-10-10, M2b, same scoped command: 451 passed, 1 skipped. New tests: typed derivation hydrates nothing and derives each chunk once; resident changes rebuild the chart store once per frame; `chunkFromRecord` adopts buffers without copying.
- Before (HEAD 65fc0161) to after, headless Chromium:

| Measure | Before | After |
|---|---|---|
| Bytes per slot, busy bag (decode + clone + `chunkFromRecord`) | 17.86 MB | 5.64 MB (2.43 heap + 3.21 typed buffers) |
| Load arrival on main thread, p50 / max | 240 / 251 ms (long tasks 126-174 ms per load) | 26 / 29 ms (no long tasks); `chunkFromRecord` <= 0.8 ms |
| Slot-arrival clone + GC self time | about 146 ms | about 22 ms per load |
| Replay heap, busy bag, 10 min ring filled | 69.9 MB | 18.0 MB |
| Five re-enter cycles | about 63.5 MB | 14.8-18.0 MB |
| Heap max while playing + digester filling | 262.7 MB | 140.7 MB |
| 7 min bag, 90 s seek storm: floor at 90 s | 52.9 MB (peaks 63.4) | 16.8 MB |
| Same, sampled max | 151.1 MB | 82.6 MB |
| Same, long-task total / worst stall | 93.7 s / 839 ms | 93.5 s / 887 ms |
| Busy-bag smoke heap at open / filled / after zoom | 47 / 48.8 / 60.5 MB | 12.1 / 13.8 / 16.9 MB |
| Page open | 6.7 s | 4.6 s |

Long-task totals did not move because headless software rendering puts 28-29 s of every 30 s in native `(program)`; our JS plus GC fell from 4.3 s to 1.0 s per 30 s on the 7 min bag. The largest remaining main-thread JS cost is NOT replay code: `getTrackingSparklineCtx` in `js/panels.js`, about 4.7-7.2 s per 30 s on the busy bag (follow-up).

- Full gate (`./run_tests.sh`, run 2026-10-10 in the replay worktree, after the audit fixes): parallel **6544 passed, 9 skipped in 285.12 s**; serial 3 passed in 10.78 s; PASS.

## Outcome

Resolved at software level: the replay working set fell about 3-4x (busy-bag ring-filled heap 69.9 to 18.0 MB; slot 17.9 to 5.6 MB), arrival work on the main thread about 10x, and the session buffer is gone. Unverified: the owner's real Win10 Chrome 154 run; worker and GPU memory (not measured); a literal 600 s ring on a long busy bag; the 3 GB crash was never reproduced headless, so it is not proven fixed. Follow-ups: the `getTrackingSparklineCtx` cost in `panels.js`; a worker-side digest if the main-thread digest shows up in the owner's trace.

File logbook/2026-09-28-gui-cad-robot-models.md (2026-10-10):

---
title: "GUI: articulated CAD robot models with browser-only axis indication"
type: feature
date: 2026-09-28
status: implemented
phase: "GUI — CAD rendering"
subsystem:
  - gui
files_changed:
  - ros_ws/gui/js/robot-meshes.js
  - ros_ws/gui/js/stewart-model.js
  - ros_ws/gui/js/ball-butler-model.js
  - ros_ws/gui/js/viewer.js
  - ros_ws/gui/js/main.js
  - ros_ws/gui/js/mocap-markers.js
  - ros_ws/gui/assets/robots/robot-parts.glb
  - ros_ws/gui/assets/robots/manifest.json
  - ros_ws/gui/test_robot_models.html
  - tools/build_gui_meshes.py
  - tests/ros/test_gui_robot_assets.py
---

# Articulated CAD robot models

Replace the schematic robots with rigid CAD parts, retaining chart selection,
fault indication, mocap markers and triads (triads draw over opaque geometry).
Jugglebot placements match the MuJoCo visual meshes; the platform consumes the
full FK rotation, and inner legs and hands translate without stretching.
The owner selected BallButler's Blender rig over the older STL assemblies.
The authored relative rest transforms of pitch and hand are preserved; the
34.5 mm CAD pivot is registered to the configured 17.5 mm pivot. Its bottom-stroke
slider pose is retained. An initial pitch-only 20-degree correction was removed
after the owner spotted the resulting hand misalignment. The rig's CAD material colours are baked into vertex colours.

## Discussion

The owner accepted a 3.2-second IDLE brightness pulse instead of transparency:
opaque CAD preserves depth and avoids blended surfaces/extra passes. CLOSED_LOOP
is steady bright, faults override red, absent/stale/other states are dim; the
View menu explains this. Indication covers the nine ODrive axes; the BB yaw
servo has no ODrive CLOSED_LOOP state and its mesh retains its CAD colour.
Pulse updates share the existing viewer loop. No subscriptions, ROS messages,
controller changes, server rendering, runtime conversion or Jetson dependencies.

## Assets and rebuild

One 19,197,932-byte static GLB, nine geometries / nineteen instances, 465,417 robot
triangles. Curved surfaces use smooth split normals, with sharp edges above 30 degrees. Leg geometry is shared; CAD materials are collapsed into one draw
call per rigid mesh. No textures, external buffers or decoder downloads.
The existing HTTP server can revalidate its cached response (no-cache does not
mean no-store); a first visit transfers the GLB. The sibling CAD checkout and
Blender are needed only for an offline rebuild on a development workstation.
Current inputs are the owner's GLBs under `temp/gui-robot-source`, replacing
the original STL/Blender inputs:

```powershell
& 'E:/Programs/Blender 5.2/blender.exe' --background --python tools/build_gui_meshes.py
```

Override `--source-dir` after `--` if needed. The committed manifest records
source SHA-256 values, registrations, triangle counts and sampled surface errors. Deploy the GUI asset directory with
the JS files; no server restart or ROS build is needed. A failed asset request
shows a visible error instead of breaking telemetry. Both robots now retain
the GLB material colours through vertex colours.

## Verification

2026-09-28, Windows 10 development workstation (not the Jetson):
- Blender 5.2 offline export completed; source CAD files were not modified.
- `pytest tests/ros/test_gui_geometry.py tests/ros/test_gui_fk_golden.py tests/ros/test_gui_robot_assets.py -q`: 147 passed (UTF-8 mode; temporary Hypothesis dependency).
- GUI/asset tests plus `tests/sim/test_logbook_front_matter.py` and `tests/sim/test_logbook_search.py`: 181 passed.
- `test_robot_models.html`: 26 real WebGL checks for all nineteen meshes, shared
  leg geometry, physical-unit offsets, FK endpoints/orientation, BB pitch/hand
  motion, status priority, freshness and retained mocap overlays.
- Synthetic CAD versus the original HEAD model modules, same browser/viewport,
  60 warmup + 240 measured animated frames each: both median 33.4 ms / p95
  33.9 ms; CAD 23 draw calls, baseline 22 (including grid and sample overlays).
  Final repeat after stale-state changes: median 33.4 ms for both, p95 33.5 ms
  CAD / 33.4 ms baseline.
  The browser was effectively capped around 30 Hz: this demonstrates no observed
  regression on this client, not a GPU headroom guarantee on other clients.
- `bash run_tests.sh` could not run here: Windows checkout CRLF parsing fails;
  the gate also targets the Jetson's Linux virtualenv. Full gate and live
  mocap/model registration still need validation on the Jetson setup.

The standalone browser check opens through the normal GUI server at
`/test_robot_models.html`, uses only synthetic data, and sends no robot commands.
For an A/B run, serve the repository root with the GUI's JS MIME handler and pass
`?baseline=/temp/gui-baseline` after extracting the old model modules with their
viewer/config imports redirected to the current viewer/config. Those temporary
baseline copies are not deployed or required by the production GUI.

## Owner feedback: quality, rig alignment and demo frames

The first reduction was too aggressive and exported flat face normals. Increased
per-part triangle budgets (especially the repeated Jugglebot legs) and exported
smooth normals across curved surfaces while keeping mechanical edges sharp.
Triangle budgets remain offline and GPU geometry remains shared. This increases
the first asset transfer from 4.6 MB to 8.4 MB, without adding runtime conversion,
extra robot messages or production mesh draw calls.

Removed the erroneous pitch-only correction: both BB parts now preserve the
Blender rig's frame-0 transforms exactly before a shared registration shift and
runtime articulation. Verified original source vertex bounds independently;
the pitch's true source top is 441.46 mm (406.96 mm relative to the 34.5 mm pivot),
within 0.4 mm of the reduced result. A geometry regression now distinguishes this
from the incorrectly straightened result, and another checks smooth normals.

The original demo supplied only one Base rigid-body sample, coincident with the
world axes. It now provides Base, moving Platform and BallButler sample poses,
with labels and all three triads visible over the meshes. The production mocap
path already retains real rigid-body poses. Grid moved to global robot Z=-82 mm;
the world origin and robot transforms remain unchanged. Demo starts CLOSED_LOOP
so CAD detail is readily visible; the IDLE button demonstrates breathing.

Jugglebot colours still need a material-bearing export: recommended Fine GLB,
uncompressed, for base/platform/leg_outer/leg_inner/hand with the existing origins
and orientations. OBJ plus its MTL files is also suitable. No new CAD export is
needed merely for the quality improvement; STL geometry already has enough detail.

2026-09-28 follow-up: GUI geometry/FK/asset tests: 148 passed. Browser checks include
the lowered grid and all three triads; refreshed preview median 33.4 ms, p95 33.5 ms.
Live Jetson validation remains pending as above.

Final follow-up verification: 182 automated tests and 27 browser assertions passed.
Same-browser A/B: CAD and schematic median/p95 both 33.4 ms; 28 versus 27 draw
calls including the three demo labels and triads. All 278,758 CAD triangles were
in view. The larger asset does not establish headroom beyond the browser cap.

## Material-bearing GLB exports and homed actuator frames

The owner supplied Onshape GLBs for all nine rigid bodies and then replaced the
inner leg and both hands with bottom-stroke exports. Jugglebot's hand is already
in the Platform frame and receives no registration shift. The inner leg's upper
joint is at source Z=708.13 mm (the new foam homing pad is included); runtime FK
still positions that joint directly, without changing robot calibration.

BB's hand is in the linear-actuator frame. Apply -90 degrees about CAD Z, then
(70.15, 0, 211) mm before the existing runtime lateral offset. The slider aligns
with the pitch rail at X=-53.5 mm, Y=-41 mm; the rail centre is at source
Z=297.5 mm. BB base/yaw shift -69 mm in Z; pitch shifts (0,41,-86.5) mm, placing
the physical pivot at the configured 17.5 mm height. No guessed hand stroke is
subtracted from the replacement exports.

The offline builder joins triangle primitives by material within each CAD
component, welds shading seams, and adaptively reduces geometry. Each candidate
is compared to the original in both directions using deterministic vertex,
face-centre, edge-midpoint and extrema samples. The threshold is 0.75 mm,
providing margin within the requested approximate 1 mm shape accuracy. This is
a sampled check, not a formal maximum-error guarantee. Long triangles on flat
surfaces are intentional. Construction lines are omitted; mechanical surface
geometry and CAD colours remain. Cached component reductions are reused across
instances and builds; these caches and original exports are not deployed.

The final scene has 465,417 triangles and the asset is 19,197,932 bytes. This is
larger than the previous STL-based asset because the new sources include many
additional components, electronics and sensors. GPU geometry remains shared,
with one material and draw call per body instance. All conversion work is offline;
the Jetson only serves a larger static file on first load. No new ROS processing
or subscriptions are introduced.

Verification: 182 automated GUI/FK/asset/logbook tests pass. All 27 browser checks
pass, including hand motion, joint registration, state indications and triads.
The local preview measured median 33.4 ms, p95 33.5 ms with all robot geometry
visible, 28 calls including demo overlays. Live Jetson validation remains pending.

Final GLB A/B check: new CAD and original schematic both measured median 33.4 ms
and p95 33.5 ms in the same browser/viewport (60 warmup + 240 measured frames).
CAD: 28 draw calls including overlays, 465,591 rendered triangles; schematic:
27 draw calls, 4,430 triangles. The roughly 30 Hz browser cap limits conclusions
about GPU headroom or performance on other clients.

## 2026-09-29: production handoff and base-joint alignment investigation

The production main.js already imports the CAD renderer; the standalone page is
only a synthetic verification harness. Ship the changed GUI JavaScript together
with assets/robots/robot-parts.glb and manifest.json. The feature remains
uncommitted on the Windows workstation. Before deployment, run the repository
Linux test gate; then update the checkout/static GUI directory served by the
Jetson and reload clients. No ROS build, firmware update, Blender installation or
CAD conversion on the Jetson is required for these frontend-only changes. Check
live telemetry articulation, mocap overlays, IDLE/CLOSED_LOOP indications and
frame times on the actual viewing client. Three.js and its loader currently use
the existing jsDelivr import map.

The apparent socket misalignment is the nominal CAD versus fitted kinematics:
source Base.glb magnet/spacer centres match the nominal CAD base nodes. Runtime
legs use BASE_NODES_MM, generated from the September 27 accepted calibration.
The six horizontal differences are 6.129, 5.598, 4.557, 6.435, 3.537 and 4.592 mm.
The hardware YAML explicitly documents these fitted nodes replacing CAD nodes.
An independent sphere fit to 5,185 lower-hemisphere source vertices of
Magnetic_Joint_Ball gives centre (0,0,64.0001665) mm and radius 12.5 mm, confirming
the existing -64 mm mesh registration. Simplification's sub-mm sampled error
cannot explain the systematic several-mm mismatch. Platform joints likewise use
fitted attachment points against nominal CAD.

No calibration or renderer changes were made during this investigation. A
presentation-only option is to articulate the visible legs between nominal CAD
attachment points, transformed by the calibrated platform pose; this closes CAD
joints but visual telescoping lengths then represent nominal geometry, not exact
calibrated joint distances. Keep the actual FK/IK and telemetry calculations on
the fitted geometry. The owner has not yet selected that presentation tradeoff.

## 2026-09-29: final leg replacements and owner alignment decision

The owner explicitly chose to retain calibrated leg attachment positions so the
CAD/socket differences remain visible. No nominal-anchor visual correction is
applied. Rebuilt both leg geometries from the replacement GLBs exported on
September 29; their authored relative rotation replaces the earlier pair.
Joint registrations remain -64 mm (outer) and -708.13 mm (inner). Source hashes
in the manifest identify the replacement files.

Final asset: 19,191,820 bytes; 462,837 robot triangles. The focused geometry,
FK, asset provenance, colour, coordinate and logbook suite passed all 182 tests.
Full Linux gate/live robot verification remains outstanding on the Jetson.

## 2026-10-10: QTM-tracked catching cone

Added `temp/gui-robot-source/Catching Cone.glb` to the offline build, with zero
registration offset: the supplied origin is the QTM rigid-body origin. The
existing `rigid_body_poses` stream drives the CAD position and orientation,
accepting `Catching_Cone` and `Catching Cone`. The mesh hides when absent,
invalid, disconnected, or without a valid pose for 1.5 seconds. A separate
View-menu group preserves manual visibility; existing markers and triads remain.
Cone markers have their own purple legend entry.

The cone reduces from 244,672 to 5,486 triangles; maximum sampled surface error
is 0.405281 mm. It adds one opaque draw call and 201,008 bytes to the bundle,
with no new ROS subscription or server-side processing. Total robot geometry
is 468,323 triangles. The original export remains ignored and is not deployed.

Validation: 148 asset/geometry/FK tests pass; whitespace check passes. The demo
now includes cone pose, rotation, loss, recovery, invalid-pose, staleness and
visibility checks, and initializes the now-separate Local Triads group. Browser verification subsequently passed all 35 checks: median 33.4 ms,
p95 33.5 ms, 30 draw calls including overlays. Live QTM alignment still needs
confirmation. The Windows preview server served JavaScript as text/plain due
to registry MIME associations. Added tools/serve_gui.py with explicit JavaScript
MIME types and no-cache preview responses. Vendored the pinned Three.js 0.170.0
module and required loaders/controls with its MIT license; both index.html and
the demo now load it locally, removing their external CDN dependency. A fresh
preview on port 8083 avoids cached incorrect MIME responses.

## 2026-10-10: BallButler hand on the FK's side of the yaw axis

After 01b6cc69 flipped `yaw_s_offset_mm` to +105.65, the render put BB's hand
2s (211 mm) to the right of its physical position. `throw_ballistics.bb_release_state`
places the hand at `s·(−sin θ, cos θ)`, which is left of the throw for positive s,
but `updateBallButler` added +s along robot +X, which is right of the +Y throw.
Under the old negative s the two errors cancelled. The fix sets the mesh offset to `−s`.
`test_robot_models.html` now asserts the FK-derived `x = −s` at identity heading,
and the misleading `test_gui_robot_assets.py` comment is corrected (its numbers
were already right).

The gate also caught 6c02b310's `catching-cone-model.js` reading `performance.now()`
without the `// wall-clock:` marker that `test_gui_clock_contract.py` requires.
It is marked, not migrated, because its staleness is compared against the render
loop's own wall-clock `now` (`viewer.js` onFrame). Behaviour is unchanged. During
a paused replay the cone still hides after 1.5 s of wall time, which is left to the replay owner.

Verification (2026-10-10): headless Chromium (SwiftShader) on
`http://localhost:8081/test_robot_models.html`: all checks PASS, including
"BB hand travel at 0/45/90 degrees". Gate result is in the commit message.

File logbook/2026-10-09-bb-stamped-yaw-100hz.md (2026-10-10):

---
title: Ball Butler yaw joins /bb/axis_estimates — stamped at sample time, 100 Hz (can-bridge FW 28, BB FW 6, additive BB_YAW_ESTIMATE)
type: feature
date: 2026-10-09
status: resolved
phase: "two-ball-skill-stack — R5 (Ball Butler calibration)"
related_plan: two-ball-skill-stack.md
files_changed:
  - config/protocol_config.yaml
  - config/generate_config.py
  - config/generate_udp_protocol.py
  - config/generated/protocol_config.h
  - config/generated/protocol_config.py
  - config/generated/udp_protocol.h
  - config/generated/udp_protocol.py
  - docs/teensy-udp-protocol.md
  - ros_ws/src/jugglebot/Teensy_code_canbridge/ball_butler_state.h
  - ros_ws/src/jugglebot/Teensy_code_canbridge/ball_butler_state.cpp
  - ros_ws/src/jugglebot/Teensy_code_canbridge/can_buses.cpp
  - ros_ws/src/jugglebot/Teensy_code_canbridge/telemetry.cpp
  - ros_ws/src/jugglebot/Teensy_code_canbridge/canbridge_config.h
  - ros_ws/src/jugglebot/Teensy_code_canbridge/protocol_config.h
  - ros_ws/src/jugglebot/Teensy_code_canbridge/udp_protocol.h
  - ros_ws/src/jugglebot/Teensy_code_platform/protocol_config.h
  - ros_ws/src/jugglebot/CatchingCone_code/protocol_config.h
  - ros_ws/src/jugglebot/jugglebot/protocol_config.py
  - ros_ws/src/jugglebot/jugglebot/teensy_bridge_node.py
  - ros_ws/src/jugglebot/jugglebot/can/ball_butler.py
  - ros_ws/gui/js/udp-traffic.js
  - teensy_link/__init__.py
  - teensy_link/protocol.py
  - teensy_link/rpc_args.py
  - tools/probes/teensy_link_profiling/jetson/udp_protocol.py
  - tests/ros/test_teensy_bridge_node_bb_yaw.py
  - tests/ros/test_ball_butler.py
  - tests/teensy_link/test_protocol_codec.py
  - tests/firmware/test_udp_protocol_xlang.py
  - tests/firmware/test_bb_fw_update_xref.py
  - logbook/2026-10-09-bb-stamped-yaw-100hz.md
  - logbook/INDEX.md
subsystem:
  - can
  - ros
  - config
tags:
  - IPC
  - testing
---

# Ball Butler yaw joins /bb/axis_estimates — stamped at sample time, 100 Hz (can-bridge FW 28, BB FW 6, additive BB_YAW_ESTIMATE)

## Summary

`/bb/axis_estimates` now carries a third JointState name, `bb_yaw` (degrees, deg/s), with the same bridge sample-time stamp and 100 Hz cadence as `bb_pitch`/`bb_hand`. BB's firmware sends a new CAN1 frame per fresh yaw sample. The can-bridge forwards it as a new, additive UDP message paired to `BB_AXIS_ESTIMATES` by an identical stamp. The 10 Hz heartbeat yaw is unchanged. Built and compiled, **not flashed**: status stays `in-progress` until both boards are flashed and the topic is checked (owner steps below). The BallButler half is `BallButler/logbook/2026-10-09-bb-stamped-yaw-100hz.md` (branch `bb-stamped-yaw-100hz`).

## Motivation

The mocap pose calibration fits the yaw-stage constellation's orientation against BB's *reported* yaw during the moving sweep. That yaw reached the Jetson only in `/bb/heartbeat`: 10 Hz, unstamped, behind three free-running ~10 Hz stages (BB CAN tx, bridge T2J, host timer). It lagged mocap by a per-session constant measured at 78–174 ms (`~/bb_calibration_sessions/bb_placement_reinvestigation_20261009/REPORT.md` §Q1), so every session had to grid-fit a latency. That report's §Q4 ranks "put the yaw into `/bb/axis_estimates`, stamped at sample time" as the single biggest robustness gain.

## The existing pitch/hand path (traced)

1. **Source.** BB's pitch and hand are ODrives (CAN1 nodes 7, 8; `NodeId::BB_PITCH/BB_HAND`). Their cyclic `Get_Encoder_Estimates` (cmd 0x09, float32 pos rev + vel rev/s) broadcast at 1 kHz. BB's Teensy does not relay them: the bridge hears them directly on CAN1. BB's own `Proprioception` holds copies for its control loop.
2. **Bridge RX.** `can_buses.cpp::on_bb_rx` → `decode_bb_odrive` → `write_pos_vel(bb_axes[i], pos, vel, micros64())` (seqlock cache, no sign flip).
3. **Bridge TX.** `telemetry.cpp::telemetry_step` at `TELEM_RATE_HZ` = 100 calls `send_bb_estimates()`. It snapshots both caches and sets `t_bridge_us = now_wall_us()`: the bridge wall clock at the snapshot, time-synced to the Jetson. It then sends `BbAxisEstimates` (MsgType 0x86, 24 B: u64 stamp + 4 × f32) on the STREAM socket. The value is the latest 1 kHz sample, so it is at most ~1 ms old at the stamp.
4. **Host.** `teensy_bridge_node._on_bb_estimates` (RX thread) unpacks the frame, queues it (4000-sample bound) and stashes the latest for robot_state. `_publish_bb_axis_estimates` (a 0.01 s timer on the executor) drains the queue into one `JointState` per sample. The stamp is `t_bridge_us` (not drain time); names are `[bb_pitch, bb_hand]`, position in rev, velocity in rev/s.
5. **Codegen.** The UDP layout is single-sourced in `config/generate_udp_protocol.py`, which emits `udp_protocol.{h,py}`, the docs, and delivered copies. The CAN ids and encodings are in `config/protocol_config.yaml` → `generate_config.py` → `protocol_config.{h,py}`, delivered to every firmware tree, **including the external `../BallButler/ball_butler_main/{protocol,hardware}_config.h`**.

The yaw is different. BB's yaw is not an ODrive: an AS5047P read in BB's 150 Hz `YawAxis` ISR feeds `Proprioception` and leaves BB only inside the 10 Hz heartbeat (0x7D1, uint16, wrapped to [0, 360), **truncated** to 0.01°). So adding it needs a BB CAN frame as well as the relay.

## Design

- **CAN (BB → bridge): `BallButlerCanId::YAW_ESTIMATE` = 0x7D8.** This is the lowest-priority BB id, so it never outranks ODrive control traffic. BB sends one frame per *fresh* 150 Hz yaw sample (deduplicated on the sample timestamp), about 1.7 % of the 1 Mbit bus. 8 bytes LE:
  - f32 `yaw_deg`: the heartbeat's quantity, unwrapped and untruncated;
  - i16 yaw velocity at `encoding.yaw_estimate.vel_res_dps` = 0.1 deg/s (±3276 deg/s, covering YawAxis's 2 rev/s glitch threshold);
  - u16 sample age at TX (µs, BB `micros64`, saturating).

  Resolution: float32 at ≤ 360° is ≤ 3e-5°, against the heartbeat's 0.01° truncation (mean bias −0.005°).
- **UDP (bridge → host): new `BB_YAW_ESTIMATE` = 0x93, 24 B.**
  - u64 `t_bridge_us`, **identical** to the same tick's `BB_AXIS_ESTIMATES`;
  - f32 `yaw_deg`;
  - f32 `yaw_vel_dps`;
  - u32 `yaw_age_us`: the sample's age at `t_bridge_us`, built only from monotonic intervals (BB sample→TX + bridge RX→emit), so a time-sync slew cannot move it;
  - u32 `bb_frames`: an RX count, for a rate/loss check.

  It is sent immediately *before* its partner, and only while a 0x7D8 frame is younger than `BB_YAW_FRESH_US` = 50 ms (otherwise silent).
- **Host.** `_on_bb_yaw_estimate` stashes the frame. `_on_bb_estimates` pairs it with its partner by **exact stamp equality** on the RX thread. The drain appends `bb_yaw` (deg, deg/s) only for a paired sample; otherwise the message keeps its old two-name shape.
- **Versions.**
  - can-bridge `FW_VERSION` 27 → 28 (`EXPECTED_BRIDGE_FW_VERSION` 28);
  - BB `FwUpdate.h FW_VERSION` 5 → 6 (`BB_FW_VERSION_EXPECTED` 6);
  - **`PROTOCOL_VERSION` stays 9.**

## Discussion

**A new msg type, not a grown `BbAxisEstimates`.** Appending yaw fields to the existing 24 B struct is the obvious minimal edit. In this protocol, though, growing a struct is an incompatible change ("as incompatible as shrinking one", `generate_udp_protocol.py`), so it would need a `PROTOCOL_VERSION` 9 → 10 bump. That bump makes `decode_frame` hard-reject *every* frame, so the whole link (legs included) goes dark until the bridge flash and host deploy land together. The additive message follows the LegCmd/HandSensor/ClockDiag precedent: either end deploys first, an old host ignores 0x93, and a new host against an FW 27 bridge publishes the unchanged two-name message. The cost is the pairing. Exact-stamp matching on the in-order RX thread makes that deterministic: it does not depend on drain timing, and a yaw is never attached to another tick's stamp (pinned by `test_yaw_from_another_tick_is_not_attached`).

**The sample age is on the wire but not in the JointState.** `bb_yaw` has the same semantics as pitch and hand: the latest sample as of the stamp. Pitch and hand are ≤ ~1 ms old (1 kHz). Yaw is sampled at 150 Hz, so it is 0–6.7 ms (hold) plus BB-loop/CAN transit older than the stamp. Expect a mean of roughly 4 ms; this is an inference from the rates, not yet measured. JointState has one stamp and no per-joint field. Rather than invent an encoding (the `effort` slot) or extrapolate the value (a model, not a measurement), the age travels in `BB_YAW_ESTIMATE.yaw_age_us` for any raw-link consumer. The REPORT's retained latency fit absorbs a constant few ms as a check (~QTM latency). If that residual matters, the follow-up is to publish the age (or the sample time) explicitly.

**The name is `bb_yaw`, not `yaw`.** It matches the existing `bb_pitch`/`bb_hand` convention on the same message.

## Implementation

- Generator, spec and regenerated artifacts: `generate_config.py --no-external` (the default run writes into the owner's `../BallButler`, which was **not** touched) and `generate_udp_protocol.py`. The BallButler headers were rendered into the BallButler worktree only, by calling `build_artifacts` with `BB_FIRMWARE_DIR` pointed there.
- The Platform and CatchingCone `protocol_config.h` copies gain the new id and namespace. Nothing reads them, and there is no behaviour change.
- `test_bb_fw_update_xref.py` gains `JUGGLEBOT_BALLBUTLER_DIR` (an override of the `../BallButler` sibling). A paired-worktree gate can then compare against the paired BallButler branch (FW 6) and not the owner's unmerged tree (FW 5). Unset, the behaviour is unchanged. **Until the BallButler branch is merged into `../BallButler`, the unset run of `test_bb_fw_version_matches_the_host_expectation` fails.** That failure is the intended tree-vs-tree skew signal, and the two branches merge together.
- The wire-layout digest in `test_udp_protocol_xlang.py` was re-pinned (additive).
- The GUI `NOMINAL_RATES` gets no `BB_YAW_ESTIMATE` row: the uplink is conditional, and a nominal rate would raise a permanent alarm whenever BB is dark.

## Verification

- Firmware compiles; nothing was flashed.
  - can-bridge (2026-10-09, `pio run -e teensy41` in `Teensy_code_canbridge/`): **SUCCESS**, `firmware.hex` built and `CanBridge::bb_yaw` present.
  - BB (2026-10-09, `pio run -e teensy40_can`, no `-t upload`, in `BallButler-yaw100/ball_butler_main/`): **SUCCESS**.
- Scoped tests (2026-10-09, `pytest -q tests/ros/test_ball_butler.py tests/ros/test_teensy_bridge_node_bb_yaw.py tests/ros/test_teensy_bridge_node_bb.py tests/teensy_link/test_protocol_codec.py tests/firmware/test_udp_protocol_xlang.py tests/ros/test_gui_geometry.py -n 4`): **301 passed**.
- Gate: 2026-10-09 21:41–21:47, `JUGGLEBOT_BALLBUTLER_DIR=/home/jetson/Desktop/BallButler-yaw100 ./run_tests.sh --full`: **PASS: 6152 passed, 9 skipped, 1 xfailed (parallel 338 s) + 6 passed (serial 23 s), total 361 s**. The env var points the BB FW-version cross-check at the paired BallButler branch (FW 6). Only this triple line changed after the run; the logbook tests were re-run on it (`pytest tests/sim/test_logbook_front_matter.py tests/sim/test_logbook_search.py`, see the commit).

## Flashing (owner — NOT executed)

ROS launch DOWN for the BB flash, because the fw-update tool owns the bridge's UDP link. Never a bare `pio run -t upload` or a loader `-s` with both Teensys on USB: `-s` reboots whichever Teensy enumerates first. teensy-hub (can-bridge, serial 19942350) = `/dev/ttyACM0`; catching cone = `/dev/ttyACM1`. Use the `/dev/serial/by-id/` paths.

1. **BB first, over CAN, through the current FW 27 bridge.** The relay is unchanged and proven. From the merged BallButler tree, `ball_butler_main/`: `pio run -e teensy40_can -t upload`; expect `FW version: 5 -> 6`. The FW 27 bridge drops 0x7D8 harmlessly (`decode_bb_odrive`: node 62 is out of range), so the stack keeps working exactly as today.
2. **Then the can-bridge, over USB, two-device-safe.** In `Teensy_code_canbridge/`, `pio run -e teensy41` (build only). Start `/home/jetson/tools/teensy_loader_cli/teensy_loader_cli --mcu=TEENSY41 -w -v .pio/build/teensy41/firmware.hex` waiting. Then reboot *only* the hub into HalfKay: `python3 -c "import serial; serial.Serial('/dev/serial/by-id/usb-Teensyduino_USB_Serial_19942350-if00',134).close()"`. Do **not** use the ini's `-s` upload_command with BB attached. Between the steps nothing breaks: the additive message means either order works. BB first keeps the BB flash on the known-good relay.
3. **Deploy the host** (merge + `colcon build`). `BRIDGE_FW_CHECK: OK — can-bridge v28` is expected; v27 is reported as a skew but never refused.
4. **Check.**
   - `ros2 topic hz /bb/axis_estimates`: ~100 Hz, unchanged.
   - `ros2 topic echo /bb/axis_estimates --once`: `name: [bb_pitch, bb_hand, bb_yaw]`, `bb_yaw` position ≈ `/bb/heartbeat` yaw (within 0.01°, after the [0, 360) wrap), velocity ≈ 0 at rest.
   - Sweep yaw and confirm `bb_yaw` leads the heartbeat yaw by ~80–170 ms.
   - Two names only means a stale/absent 0x7D8: BB still on FW 5, or BB dark.

## Flash record and wire check (2026-10-10)

- **BB flashed to FW 6 over CAN, 2026-10-09 23:44** (BallButler `main` `c99ce96`; through the
  FW 27 bridge, 25.3 s, `FW version: 5 -> 6`). The ini's tool path had to be the live
  checkout's (`~/Desktop/Jugglebot-skills/tools/teensy_link_bridge.py`); BallButler `587e732`
  points it there.
- **Can-bridge flashed to FW 28 over USB, 2026-10-10 00:01** from this branch (`02abfe49`):
  `pio run -e teensy41`, waiting `teensy_loader_cli --mcu=TEENSY41 -w -v`, 134-baud touch of
  the hub's by-id port only (`BRIDGE_IDENTITY` reports 28, link UP, uptime reset).
- **Raw-link check with BB on** (`BallButler/ball_butler_main/scripts/bb_link_check.py`, no
  ROS, 5 s window): `BB_YAW_ESTIMATE` 99.9 Hz beside `BB_AXIS_ESTIMATES` 99.9 Hz, **500/500
  stamps paired**; `yaw_age_us` min 21 µs, median 3.0 ms, p95 3.0 ms, max 6.05 ms (the 150 Hz
  sample-and-hold prediction: 0–6.7 ms); stamped yaw −2.9° while the heartbeat read 357.13°
  (the same angle before the [0, 360) wrap); BB bus 457 frames/s, +150 over a BB FW 5 bag.
- **Closed 2026-10-10:** `/bb/axis_estimates` has carried `bb_yaw` at 100 Hz on every launch since the
  bridge flash, and every BB calibration from the 13:45 sitting on ran with `yaw source stamped` (bb_yaw lag
  against mocap −0.2…+2.5 ms per sweep, where the heartbeat had lagged 78–174 ms per session);
  `bb_yaw_source` defaults to `auto` since 308e0b8b. The accuracy pay-off is in
  [2026-10-10-bb-yaw-offset-spread-stamped-source](2026-10-10-bb-yaw-offset-spread-stamped-source.md) and
  [2026-10-10-bb-base-marker-frame](2026-10-10-bb-base-marker-frame.md).
- **Caveat, tracked in BallButler `logbook/2026-10-10-bb-hand-torque-ff-scale.md`:** the BB FW 6 build that
  carries 0x7D8 regenerated `protocol_config.h` from this checkout and so took `input_scales.hand_tor` (1000,
  Jugglebot's hand ODrive Pro) for BB's own hand ODrive S1 (configured 100): BB's hand torque feedforward has
  gone out ×10 since the flash (pre-throw kick, 215 mm strokes, spinouts, throws ~7 % slow, landings 120 mm
  short in the 2026-10-10 14:49 sitting). The stamped yaw itself is unaffected. The proposed fix adds
  `bb_hand_vel` / `bb_hand_tor` to `config/protocol_config.yaml` and regenerates (BB FW 7,
  `BB_FW_VERSION_EXPECTED` 7) — a separate entry when it lands.
- Seen at rest (yaw motor unpowered): the stamped yaw crept 0.2° over 5 s with a reported
  −0.8 °/s. Physical creep of the unpowered stage rather than encoder noise, by its size;
  harmless to the moving-sweep estimator, unexplained.

## Open Questions / Follow-ups

- Hardware check (step 4), then flip to `resolved`.
- `yaw_age_us` measured 2026-10-10: median 3.0 ms, max 6.05 ms (above). Decide whether to publish it or correct for it.
- The calibration consumer (`mocap_node` BB pose fit) still reads heartbeat yaw. Switching it to `bb_yaw` is the next unit.

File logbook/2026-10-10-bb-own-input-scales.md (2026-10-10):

---
title: Ball Butler gets its own CAN input scales (bb_hand_* 100/100, bb_pitch_* 1000/1000) — BB FW 6 had borrowed Jugglebot's hand_tor (1000) for BB's hand S1 (input_torque_scale 100), a 10x torque feedforward; BB_FW_VERSION_EXPECTED 6 -> 7
type: bugfix
date: 2026-10-10
status: resolved
phase: "two-ball-skill-stack — R5 (Ball Butler calibration)"
related_plan: two-ball-skill-stack.md
files_changed:
  - config/protocol_config.yaml
  - config/generated/protocol_config.h
  - config/generated/protocol_config.py
  - ros_ws/src/jugglebot/jugglebot/protocol_config.py
  - ros_ws/src/jugglebot/Teensy_code_platform/protocol_config.h
  - ros_ws/src/jugglebot/Teensy_code_canbridge/protocol_config.h
  - ros_ws/src/jugglebot/CatchingCone_code/protocol_config.h
  - teensy_link/rpc_args.py
  - logbook/2026-10-10-bb-own-input-scales.md
  - logbook/INDEX.md
subsystem:
  - config
  - can
tags:
  - safety
---

# Ball Butler gets its own CAN input scales

## Problem

BB FW 6 (BallButler `f296441`) regenerated `ball_butler_main/protocol_config.h`
from this repo. Its `InputScale::hand_tor` is 1000, Jugglebot's hand ODrive Pro
value since FW 22 (`75030f73`, with `odrive_pro_hand_config.json`); FW 5's copy
had 100. BB's `CanInterface` scaled set_input_pos `vel_ff` / `tor_ff` for EVERY
node by `InputScale::hand_vel` / `hand_tor`, and BB's hand drive (ODrive S1,
node 8) is configured `input_torque_scale = 100` (`odrive_s1_bb_hand_config.json`;
the owner read 100 off node 8 with odrivetool). Every BB hand torque
feedforward has been sent at 10x since FW 6: pre-throw kicks, spinouts,
215 mm strokes, throws 7 % slow. Analysis:
`~/bb_calibration_sessions/hand_jolt_20261010/REPORT.md`; BallButler logbook
`2026-10-10-bb-hand-torque-ff-scale.md`.

## Root Cause

One set of keys served two different drives. `hand_*` documents Jugglebot's
hand Pro; BB's firmware reused it for its own S1, so a change made correctly
for one drive silently changed the other. Nothing on either side compared the
borrowed scale with BB's drive.

## Change

Owner's principle: each axis with unique limits has its own set of keys.

- `config/protocol_config.yaml` `encoding.input_scales`: new
  `bb_hand_vel: 100.0`, `bb_hand_tor: 100.0` (BB hand, node 8, ODrive S1;
  matches `odrive_s1_bb_hand_config.json`) and `bb_pitch_vel: 1000.0`,
  `bb_pitch_tor: 1000.0` (BB pitch, node 7, ODrive Micro; matches BallButler's
  `bb_pitch_odrive_micro_config.json`). Jugglebot's `hand_*` / `leg_*` are
  unchanged. Regenerated with `config/generate_config.py --no-external` (the
  default write path would have written into the owner's `../BallButler`
  main tree from this worktree); the header was copied into the BallButler
  FW 7 worktree by hand.
- BB axis audit (`ball_butler_main/`): the only scaled feedforward is
  `CanInterface::sendInputPos`. Hand (node 8): streamed vel/tor FF from
  `HandTrajectoryStreamer`, gets `bb_hand_*`. Pitch (node 7): `PitchAxis`
  sends `vel_ff = tor_ff = 0` (TRAP_TRAJ), so its scale is wire-inert today;
  it gets its own keys anyway so it can never inherit the hand's. Caveat: the
  pitch config file is a 2026-03 snapshot whose `node_id` reads 0 (live drive
  is 7), so 1000/1000 is not confirmed on the live drive. Yaw is a brushed DC
  motor on an H-bridge (PWM), not an ODrive: no keys. `sendInputVel` (homing)
  sends floats, not scaled ints: no keys needed.
- `teensy_link/rpc_args.py`: `BB_FW_VERSION_EXPECTED` 6 -> 7.
  `EXPECTED_BRIDGE_FW_VERSION` stays 28 (the bridge does not change).
- Host side audited: no Python or can-bridge code decodes or encodes BB's
  set_input_pos with a scale (`INPUT_SCALE_HAND_*` consumers are all
  Jugglebot's hand, axis 6). Nothing else to fix.

Not done: an at-arm SDO readback of the S1's `axis0.config.can.input_torque_scale`.
No authoritative local source gives the S1 0.6.11 endpoint id (odrivetool's
cached ELFs embed endpoint trees, but none matches the S1 0.6.11 ids the repo
has proven, `get_gpio_states` 700 / `commutation_mapper.pos_abs` 488).
Follow-up in the BallButler entry.

## Verification

See the commit's `Tests:` lines. Hardware verification is owed: flash BB FW 7,
confirm the fw-update tool's `FW version: 6 -> 7` receipt, and a throwing
sitting with normal strokes and launch speed.

external_changes: BallButler branch `bb-fw7-own-hand-scales` —
`ball_butler_main/protocol_config.h` (copied, + `InputScale::bb_*`),
`ball_butler_main/CanInterface.{h,cpp}` (per-node scales), `ball_butler_main/FwUpdate.h`
(FW_VERSION 7), `logbook/2026-10-10-bb-hand-torque-ff-scale.md`, `logbook/INDEX.md`.

**Flashed 2026-10-10 17:21 local:** BB FW 7 went over CAN from the merged BallButler `main` (`da3bfbe`) with this
checkout's `tools/teensy_link_bridge.py --fw-update --target bb` (163 840 B in 25.4 s, 26 rewinds, VERIFY OK, receipt
`FW version: 6 -> 7`); `bb_link_check.py` afterwards: bridge FW 28, BB on the bus, `bb_yaw` 99.8 Hz, 401/401 paired.
`test_bb_fw_update_xref.py` + `test_udp_protocol_xlang.py` against the merged BallButler tree: 49 passed;
`generate_config.py --check`: CONFIG FRESH. This entry's scope (the keys, the regeneration, the expected version) is
live; the behavioural verification of the hand (rest ~+0.46 mm after a reload, no pre-throw kick, stroke ~236 mm, no
spinouts, then the 40-throw validation) is the owner's first FW 7 sitting, tracked in BallButler
`logbook/2026-10-10-bb-hand-torque-ff-scale.md`.

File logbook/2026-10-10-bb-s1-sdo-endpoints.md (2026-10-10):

---
title: Ball Butler's hand ODrive S1 gets its own SDO endpoint ids from the S1 0.6.11-1 table (can.input_torque_scale 273, input_vel_scale 272, node_id 262, fw/hw version 10-12/6-7) for BB FW 8's at-arm input-scale guard; the S1 commutation_mapper_pos_abs was 488 (= task_times.can_heartbeat.length), now 451; BB_FW_VERSION_EXPECTED 7 -> 8
type: bugfix
date: 2026-10-10
status: resolved
phase: "two-ball-skill-stack — R5 (Ball Butler calibration)"
related_plan: two-ball-skill-stack.md
related_entries:
  - 2026-10-10-bb-own-input-scales
  - 2026-07-29-hand-sensor-endpoint-id-contract
files_changed:
  - config/protocol_config.yaml
  - config/generated/protocol_config.h
  - config/generated/protocol_config.py
  - ros_ws/src/jugglebot/jugglebot/protocol_config.py
  - ros_ws/src/jugglebot/Teensy_code_platform/protocol_config.h
  - ros_ws/src/jugglebot/Teensy_code_canbridge/protocol_config.h
  - ros_ws/src/jugglebot/CatchingCone_code/protocol_config.h
  - "config/ODrive config Files/odrive-s1-0.6.11-1_flat_endpoints.json"
  - teensy_link/rpc_args.py
  - logbook/2026-10-10-bb-s1-sdo-endpoints.md
  - logbook/INDEX.md
external_changes:
  - "BallButler branch bb-fw8-sdo-scale-guard: ball_butler_main/protocol_config.h (copied from config/generated/), ball_butler_main/CanInterface.h, ball_butler_main/CanInterface.cpp (the hand input-scale guard), ball_butler_main/FwUpdate.h (FW_VERSION 7 -> 8), logbook/2026-10-10-bb-hand-torque-ff-scale.md, logbook/INDEX.md"
subsystem:
  - config
  - can
tags:
  - safety
---

# Ball Butler's hand S1 gets its own SDO endpoint ids

## Problem

BB FW 7 (`2026-10-10-bb-own-input-scales`) gave Ball Butler its own CAN input
scales but nothing compares them with the drive: the at-arm SDO readback of
node 8's `axis0.config.can.input_torque_scale` was deferred because no
authoritative ODrive S1 0.6.11 endpoint table was in either repo. The only
`input_torque_scale` id here was the Pro's (283; in the S1 table 283 is
`axis0.config.P_bus_soft_max`).

The owner has now supplied the S1 table:
`odrive-s1-0.6.11-1_flat_endpoints.json` (fw_version 0.6.11-1, hw_version
5.2.0, tree crc 52326, 631 endpoints).

## Change

- The table is committed as `config/ODrive config Files/odrive-s1-0.6.11-1_flat_endpoints.json`
  (sha256 `f9907410…2944ef6`, byte-identical to the owner's copy in
  `~/bb_calibration_sessions/hand_jolt_20261010/`). It is the source of every
  id in `endpoints.odrive_s1_0_6_11`, as the Pro's table is for the Pro's block.
- `config/protocol_config.yaml` `endpoints.odrive_s1_0_6_11` (the existing S1
  block; the Pro block is untouched) gains `can_input_torque_scale: 273`,
  `can_input_vel_scale: 272` (uint32 rw), `can_node_id: 262`,
  `fw_version_major/minor/revision: 10/11/12`, `hw_version_major/minor: 6/7`,
  with a comment naming the file and its fw/hw version. Every id in the block
  was checked against the table by a script (all 10 equal).
- **`commutation_mapper_pos_abs` 488 -> 451.** The block's comment said its
  values were "proven in production on BB"; that holds for `get_gpio_states`
  700 (BB's ball-in-hand poll invokes it every session) but not for 488. In the
  S1 0.6.11-1 table 488 is `axis0.task_times.can_heartbeat.length`;
  `axis0.commutation_mapper.pos_abs` is 451 (`axis0.pos_vel_mapper.pos_abs` is
  429). Nothing sends it: BB's only user, `CanInterface::isEncoderSearchComplete`,
  is never called, and no Jugglebot firmware uses the S1 block. Only
  `tests/firmware/test_gpio_poll_xref.py` reads the Python constant, as a
  bare-literal screen. 488 most likely came from an older S1 firmware build
  (BallButler `zTesting/sensored_hand_testing/CanInterface.h`, copied from this
  repo 2026-03-19, hardcodes 488/700); the `pDOE…` ELF in
  `~/.cache/odrivetool/firmware/` has pos_abs at 488 but gpio at 675, so no
  known build has both 488 and 700.
- Regenerated with `config/generate_config.py --no-external`; the header was
  copied into the BallButler FW 8 worktree by hand. The header diff is the S1
  block only (8 added lines, 488 -> 451).
- `teensy_link/rpc_args.py` `BB_FW_VERSION_EXPECTED` 7 -> 8, with a history
  line. Nothing else on the Python/ROS side pins BB's FW version
  (`tests/teensy_link/test_rpc.py`'s `== 7` is a scripted INFO reply value);
  `EXPECTED_BRIDGE_FW_VERSION` stays 28.
- BB FW 8 (BallButler `logbook/2026-10-10-bb-hand-torque-ff-scale.md`): at every
  CLOSED_LOOP request to the hand it SDO-READs (opcode 0, the frame
  `odrive_protocol.h encode_sdo_read` builds) 273, 272, 262, 10, 11, 12, one at
  a time, and zeroes node 8's `set_input_pos` vel_ff/tor_ff while a scale reads
  back different from `bb_hand_tor` / `bb_hand_vel`. USB serial only; no frame
  layout changes.

## Verification

- `generate_config.py --check`: CONFIG FRESH, 14 artifacts; one EXTERNAL DRIFT
  line for `../BallButler/ball_butler_main/protocol_config.h` (the owner's main
  tree, until the BallButler branch merges): expected.
- Tests: see the commit's `Tests:` lines.
- Not verified here (no hardware): that BB's hand drive actually runs S1
  0.6.11-1. FW 8 prints the drive's fw version and node_id on its first check.

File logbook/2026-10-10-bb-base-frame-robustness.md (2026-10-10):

---
title: BB base-marker frame hardened after its first sittings — identification searches every marker but BB's own (a QTM label grab no longer blinds it), a missing base leads the refusal instead of `bb_moved`, and κ is pooled robustly (per-source MAD clip) behind a tighter gate (Δκ floor 0.15° → 0.09°)
type: bugfix
date: 2026-10-10
status: resolved
phase: "two-ball-skill-stack — R5 (Ball Butler calibration)"
related_plan: two-ball-skill-stack.md
files_changed:
  - ros_ws/src/jugglebot/jugglebot/bb_base_frame.py
  - ros_ws/src/jugglebot/jugglebot/mocap_node.py
  - ros_ws/src/jugglebot/resources/bb_base_frame.json
  - tools/bb_base_frame_build.py
  - tests/ros/test_bb_base_frame.py
  - tests/ros/test_mocap_node_base_frame.py
  - tests/ros/test_mocap_node_keep_last_good.py
  - tests/ros/test_mocap_node_yaw_gate.py
  - tests/ros/test_perception_console_lines.py
  - logbook/2026-10-10-bb-base-frame-robustness.md
  - logbook/2026-10-10-bb-base-marker-frame.md
  - logbook/INDEX.md
subsystem:
  - tracking
  - ros
tags:
  - testing
---

# BB base-marker frame robustness
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

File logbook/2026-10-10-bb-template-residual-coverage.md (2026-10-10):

---
title: BB template residual is pose-binned, so QTM's pose-dependent reconstruction error at BB's location no longer reads as a moved marker; the 5 sweeps of 2026-10-10_10-32-31 refused TEMPLATE_RESIDUAL now pass, a real displacement still refuses
type: bugfix
date: 2026-10-10
status: resolved
phase: "two-ball-skill-stack — R5 (Ball Butler calibration)"
related_plan: two-ball-skill-stack.md
files_changed:
  - ros_ws/src/jugglebot/jugglebot/bb_calibration.py
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

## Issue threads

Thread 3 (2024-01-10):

Solidwork CAD Files

TGiles1998, 2024-01-10:
Hi Harrison,

Thank you for the great work you have done on the linear actuators!

Would it be possible to share the solidworks files for these by any chance?

many thanks,

Thomas

Jugleer, 2024-01-12:
Hey Thomas!

I've been internally debating whether to share these files or not and have (for the time being) landed on not sharing them as it would make it much more plausible for someone(s) to take the design, make minor changes, and rebrand it as their own. Sharing only the .3MF files seemed like a good middle-ground to me, as it gives access to the objects, without the ability to (easily) make minor changes.

Though now that I think about it, the SolidWorks "Maker" licence would mean that only other "makers" could open the files, which I'm more on-board with 🤔

Out of curiosity, what do you plan to do with the SW files?

TGiles1998, 2024-01-12:
No I totally respect that as you should get full credit for all the hard work you have done! My interest is in the actuators primarily as I started designing something similar to yours as I know I wanted to use carbon fibre tube with rollers for a really low inertia system. I then found yours and you were much further ahead and had very kindly put the printed parts out so I've now built one of the actuators. I'm currently undertaking a PhD in marine renewable energy and I'd like to use a similar system, but quite modified, for 6DoF a marine structure in a tank. The SW files were really just for my interest to understand the system further as my system will have to be quite different. But I have now since found the .step assembly which will more than serve the purpose. I am very happy to share my progress on my system and will of course give you credit for the great help you have shared! Many thanks, Thomas

Jugleer, 2024-01-19:
Haha awesome! I'm happy to hear that there exists another of my actuators somewhere out there in the world. Very cool feeling 🤗

I'm glad that the .step file will suit your purposes 😊 I'm still pondering this but I'm honestly leaning more towards sharing full CAD files in the future. I might go back and do the same for these actuators but I like to make sure that the things I'm publishing are easy to use/understand so organising all the files in a sensible way will take some time...

If you happen to have other questions etc. about the actuators (or want to see what modifications other people have suggested), you should head to this project's Zulip site (https://pdj.zulipchat.com/) and I'll happily chime in where possible 😊

Best of luck with your PhD!!

TGiles1998, 2024-01-19:
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

I've attached a pic of the one I built.

Will do and thanks!

Closed 2024-01-19.

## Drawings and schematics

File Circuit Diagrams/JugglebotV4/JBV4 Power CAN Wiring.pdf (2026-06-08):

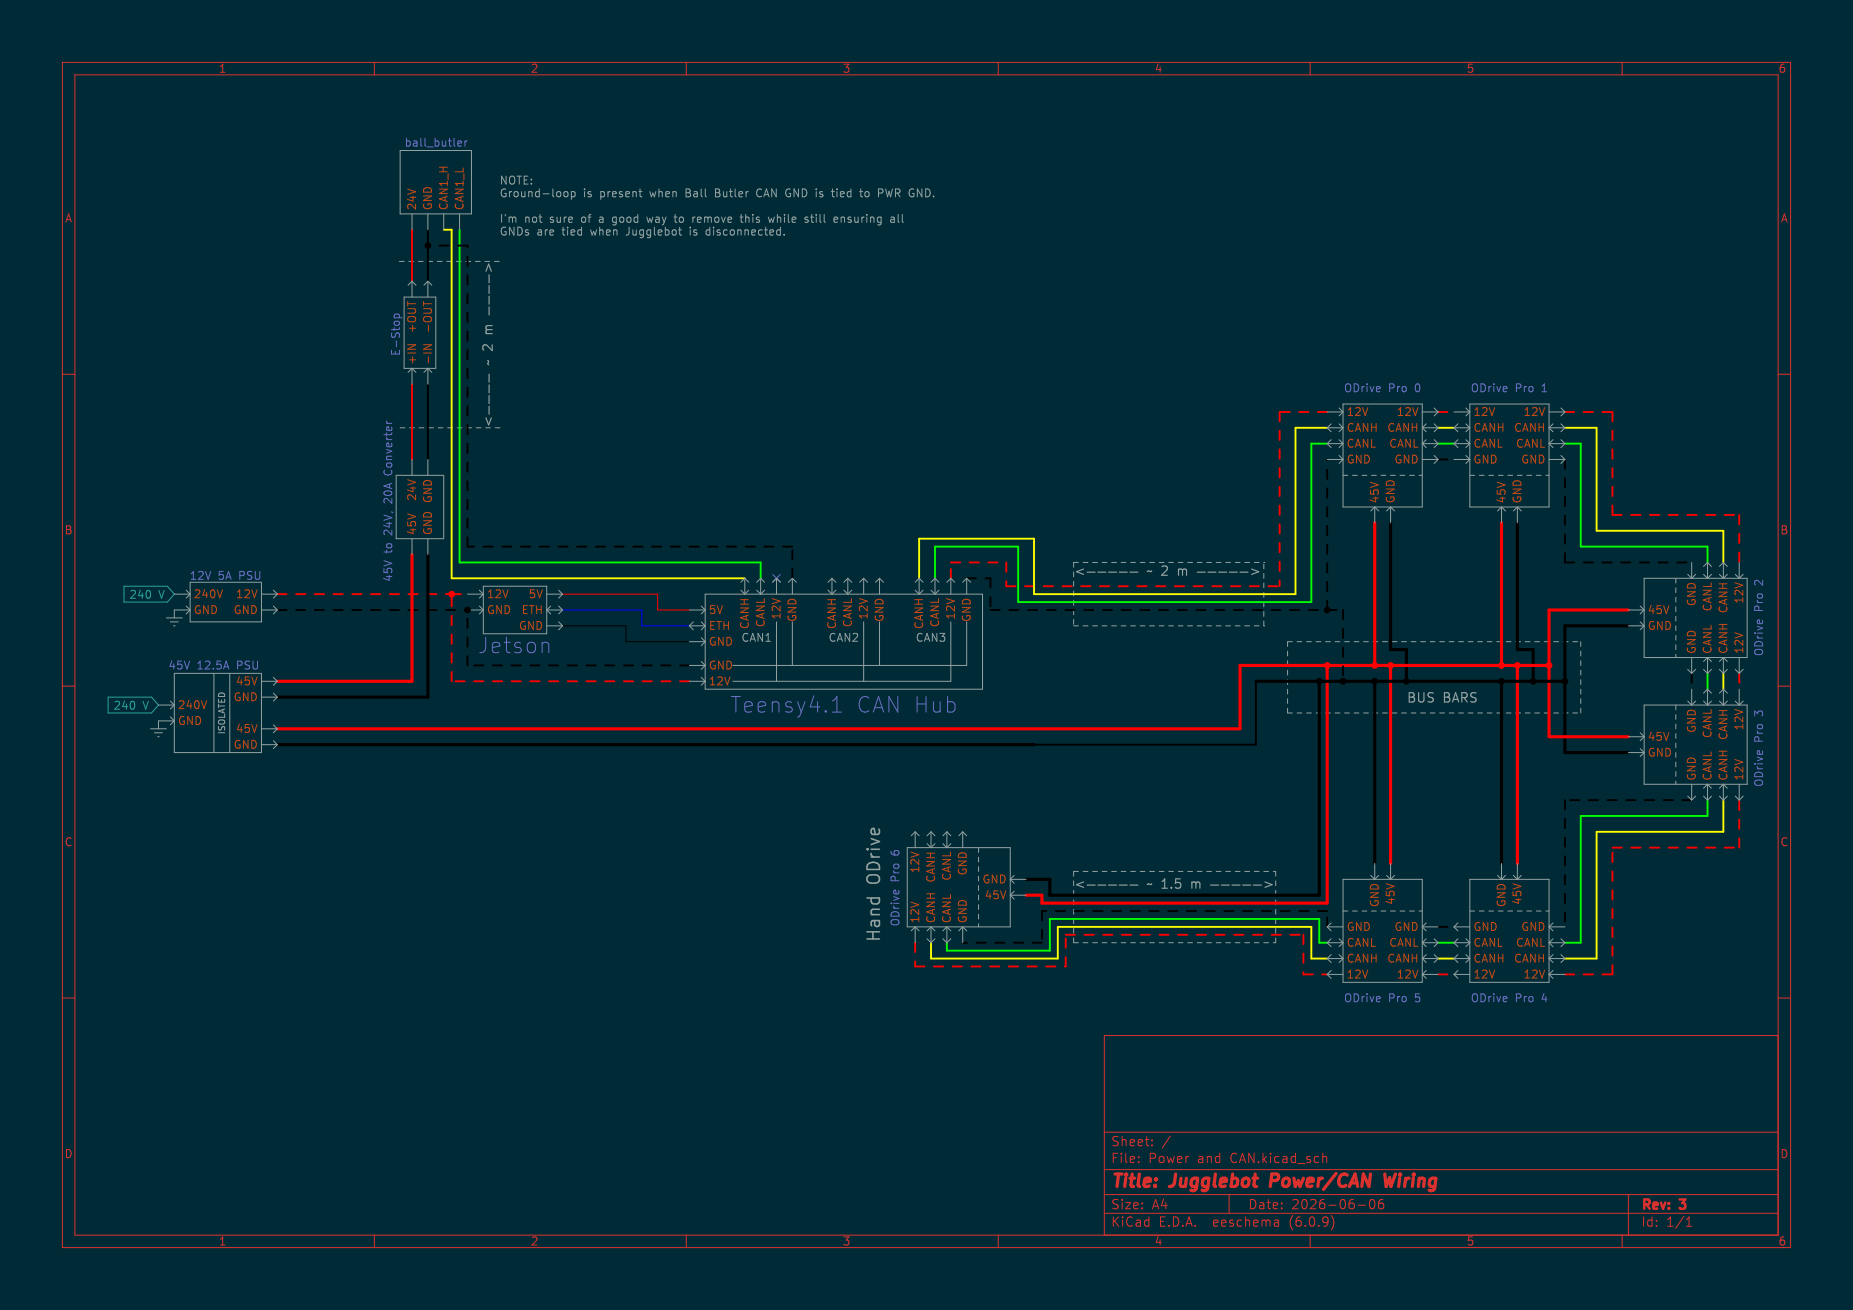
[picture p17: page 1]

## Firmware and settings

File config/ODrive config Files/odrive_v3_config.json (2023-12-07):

{"axis0": {"acim_estimator": {"config": {"slip_velocity": 14.706000328063965}}, "config": {"dir_gpio_pin": 2, "enable_sensorless_mode": false, "enable_step_dir": false, "enable_watchdog": false, "startup_closed_loop_control": false, "startup_encoder_index_search": true, "startup_encoder_offset_calibration": false, "startup_homing": false, "startup_motor_calibration": false, "step_dir_always_on": false, "step_gpio_pin": 1, "watchdog_timeout": 0.0, "calibration_lockin": {"accel": 20.0, "current": 10.0, "ramp_distance": 3.1415927410125732, "ramp_time": 0.4000000059604645, "vel": 40.0}, "can": {"bus_vi_rate_ms": 0, "controller_error_rate_ms": 0, "encoder_count_rate_ms": 0, "encoder_error_rate_ms": 0, "encoder_rate_ms": 10, "heartbeat_rate_ms": 100, "iq_rate_ms": 10, "is_extended": false, "motor_error_rate_ms": 0, "node_id": 0, "sensorless_error_rate_ms": 0, "sensorless_rate_ms": 0}, "general_lockin": {"accel": 20.0, "current": 10.0, "finish_distance": 100.0, "finish_on_distance": false, "finish_on_enc_idx": false, "finish_on_vel": false, "ramp_distance": 3.1415927410125732, "ramp_time": 0.4000000059604645, "vel": 40.0}, "sensorless_ramp": {"accel": 200.0, "current": 10.0, "finish_distance": 100.0, "finish_on_distance": false, "finish_on_enc_idx": false, "finish_on_vel": true, "ramp_distance": 3.1415927410125732, "ramp_time": 0.4000000059604645, "vel": 400.0}}, "controller": {"config": {"axis_to_mirror": 255, "circular_setpoint_range": 1.0, "circular_setpoints": false, "control_mode": 3, "electrical_power_bandwidth": 20.0, "enable_gain_scheduling": false, "enable_overspeed_error": true, "enable_torque_mode_vel_limit": true, "enable_vel_limit": true, "gain_scheduling_width": 10.0, "homing_speed": 0.25, "inertia": 0.0, "input_filter_bandwidth": 2.0, "input_mode": 5, "load_encoder_axis": 0, "mechanical_power_bandwidth": 20.0, "mirror_ratio": 1.0, "pos_gain": 40.0, "spinout_electrical_power_threshold": 10.0, "spinout_mechanical_power_threshold": -10.0, "steps_per_circular_range": 1024, "torque_mirror_ratio": 0.0, "torque_ramp_rate": 0.009999999776482582, "vel_gain": 0.20000000298023224, "vel_integrator_gain": 0.3199999928474426, "vel_integrator_limit": Infinity, "vel_limit": 60.0, "vel_limit_tolerance": 1.2000000476837158, "vel_ramp_rate": 1.0, "anticogging": {"anticogging_enabled": true, "calib_anticogging": false, "calib_pos_threshold": 1.0, "calib_vel_threshold": 1.0, "cogging_ratio": 1.0, "index": 0, "pre_calibrated": false}}}, "encoder": {"config": {"abs_spi_cs_gpio_pin": 1, "bandwidth": 1000.0, "calib_range": 0.019999999552965164, "calib_scan_distance": 50.26548385620117, "calib_scan_omega": 12.566370964050293, "cpr": 8192, "direction": -1, "enable_phase_interpolation": true, "find_idx_on_lockin_only": false, "hall_polarity_calibrated": false, "hall_polarity": 0, "ignore_illegal_hall_state": false, "index_offset": 0.0, "mode": 0, "phase_offset_float": 0.3224778175354004, "phase_offset": -4900, "pre_calibrated": true, "sincos_gpio_pin_cos": 4, "sincos_gpio_pin_sin": 3, "use_index_offset": true, "use_index": true}}, "max_endstop": {"config": {"debounce_ms": 50, "enabled": false, "gpio_num": 0, "is_active_high": false, "offset": 0.0}}, "mechanical_brake": {"config": {"gpio_num": 0, "is_active_low": true}}, "min_endstop": {"config": {"debounce_ms": 50, "enabled": false, "gpio_num": 0, "is_active_high": false, "offset": 0.0}}, "motor": {"config": {"I_bus_hard_max": Infinity, "I_bus_hard_min": -Infinity, "I_leak_max": 0.10000000149011612, "R_wL_FF_enable": false, "acim_autoflux_attack_gain": 10.0, "acim_autoflux_decay_gain": 1.0, "acim_autoflux_enable": false, "acim_autoflux_min_Id": 10.0, "acim_gain_min_flux": 10.0, "bEMF_FF_enable": false, "calibration_current": 10.0, "current_control_bandwidth": 1000.0, "current_lim_margin": 8.0, "current_lim": 20.0, "dc_calib_tau": 0.20000000298023224, "inverter_temp_limit_lower": 100.0, "inverter_temp_limit_upper": 120.0, "motor_type": 0, "phase_inductance": 2.394548209849745e-05, "phase_resistance": 0.04819115251302719, "pole_pairs": 7, "pre_calibrated": true, "requested_current_range": 60.0, "resistance_calib_max_voltage": 2.0, "torque_constant": 0.05513330176472664, "torque_lim": Infinity}, "fet_thermistor": {"config": {"enabled": true, "temp_limit_lower": 100.0, "temp_limit_upper": 120.0}}, "motor_thermistor": {"config": {"enabled": false, "gpio_pin": 4, "poly_coefficient_0": 0.0, "poly_coefficient_1": 0.0, "poly_coefficient_2": 0.0, "poly_coefficient_3": 0.0, "temp_limit_lower": 100.0, "temp_limit_upper": 120.0}}}, "sensorless_estimator": {"config": {"observer_gain": 1000.0, "pll_bandwidth": 1000.0, "pm_flux_linkage": 0.0015800000401213765}}, "trap_traj": {"config": {"accel_limit": 10.0, "decel_limit": 10.0, "vel_limit": 10.0}}}, "axis1": {"acim_estimator": {"config": {"slip_velocity": 14.706000328063965}}, "config": {"dir_gpio_pin": 8, "enable_sensorless_mode": false, "enable_step_dir": false, "enable_watchdog": false, "startup_closed_loop_control": false, "startup_encoder_index_search": true, "startup_encoder_offset_calibration": false, "startup_homing": false, "startup_motor_calibration": false, "step_dir_always_on": false, "step_gpio_pin": 7, "watchdog_timeout": 0.0, "calibration_lockin": {"accel": 20.0, "current": 10.0, "ramp_distance": 3.1415927410125732, "ramp_time": 0.4000000059604645, "vel": 40.0}, "can": {"bus_vi_rate_ms": 0, "controller_error_rate_ms": 0, "encoder_count_rate_ms": 0, "encoder_error_rate_ms": 0, "encoder_rate_ms": 10, "heartbeat_rate_ms": 100, "iq_rate_ms": 10, "is_extended": false, "motor_error_rate_ms": 0, "node_id": 1, "sensorless_error_rate_ms": 0, "sensorless_rate_ms": 0}, "general_lockin": {"accel": 20.0, "current": 10.0, "finish_distance": 100.0, "finish_on_distance": false, "finish_on_enc_idx": false, "finish_on_vel": false, "ramp_distance": 3.1415927410125732, "ramp_time": 0.4000000059604645, "vel": 40.0}, "sensorless_ramp": {"accel": 200.0, "current": 10.0, "finish_distance": 100.0, "finish_on_distance": false, "finish_on_enc_idx": false, "finish_on_vel": true, "ramp_distance": 3.1415927410125732, "ramp_time": 0.4000000059604645, "vel": 400.0}}, "controller": {"config": {"axis_to_mirror": 255, "circular_setpoint_range": 1.0, "circular_setpoints": false, "control_mode": 3, "electrical_power_bandwidth": 20.0, "enable_gain_scheduling": false, "enable_overspeed_error": true, "enable_torque_mode_vel_limit": true, "enable_vel_limit": true, "gain_scheduling_width": 10.0, "homing_speed": 0.25, "inertia": 0.0, "input_filter_bandwidth": 2.0, "input_mode": 5, "load_encoder_axis": 1, "mechanical_power_bandwidth": 20.0, "mirror_ratio": 1.0, "pos_gain": 40.0, "spinout_electrical_power_threshold": 10.0, "spinout_mechanical_power_threshold": -10.0, "steps_per_circular_range": 1024, "torque_mirror_ratio": 0.0, "torque_ramp_rate": 0.009999999776482582, "vel_gain": 0.20000000298023224, "vel_integrator_gain": 0.3199999928474426, "vel_integrator_limit": Infinity, "vel_limit": 60.0, "vel_limit_tolerance": 1.2000000476837158, "vel_ramp_rate": 1.0, "anticogging": {"anticogging_enabled": true, "calib_anticogging": false, "calib_pos_threshold": 1.0, "calib_vel_threshold": 1.0, "cogging_ratio": 1.0, "index": 0, "pre_calibrated": true}}}, "encoder": {"config": {"abs_spi_cs_gpio_pin": 1, "bandwidth": 1000.0, "calib_range": 0.019999999552965164, "calib_scan_distance": 50.26548385620117, "calib_scan_omega": 12.566370964050293, "cpr": 8192, "direction": -1, "enable_phase_interpolation": true, "find_idx_on_lockin_only": false, "hall_polarity_calibrated": false, "hall_polarity": 0, "ignore_illegal_hall_state": false, "index_offset": 0.0, "mode": 0, "phase_offset_float": -0.4523690342903137, "phase_offset": -4663, "pre_calibrated": true, "sincos_gpio_pin_cos": 4, "sincos_gpio_pin_sin": 3, "use_index_offset": true, "use_index": true}}, "max_endstop": {"config": {"debounce_ms": 50, "enabled": false, "gpio_num": 0, "is_active_high": false, "offset": 0.0}}, "mechanical_brake": {"config": {"gpio_num": 0, "is_active_low": true}}, "min_endstop": {"config": {"debounce_ms": 50, "enabled": false, "gpio_num": 0, "is_active_high": false, "offset": 0.0}}, "motor": {"config": {"I_bus_hard_max": Infinity, "I_bus_hard_min": -Infinity, "I_leak_max": 0.10000000149011612, "R_wL_FF_enable": false, "acim_autoflux_attack_gain": 10.0, "acim_autoflux_decay_gain": 1.0, "acim_autoflux_enable": false, "acim_autoflux_min_Id": 10.0, "acim_gain_min_flux": 10.0, "bEMF_FF_enable": false, "calibration_current": 10.0, "current_control_bandwidth": 1000.0, "current_lim_margin": 8.0, "current_lim": 20.0, "dc_calib_tau": 0.20000000298023224, "inverter_temp_limit_lower": 100.0, "inverter_temp_limit_upper": 120.0, "motor_type": 0, "phase_inductance": 2.3538314053439535e-05, "phase_resistance": 0.046579450368881226, "pole_pairs": 7, "pre_calibrated": true, "requested_current_range": 60.0, "resistance_calib_max_voltage": 2.0, "torque_constant": 0.05513330176472664, "torque_lim": Infinity}, "fet_thermistor": {"config": {"enabled":
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

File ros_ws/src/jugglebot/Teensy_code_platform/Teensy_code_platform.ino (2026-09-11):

/*****************************************************************************************
 *  Teensy 4.0 — Jugglebot “platform” microcontroller
 *  ------------------------------------------------------------------
 *  Functions already present:
 *    • CAN traffic monitor (ID 0x7DF)
 *    • Optional debugging of specific CAN IDs
 *    • Timed analysis of RxSdo messages
 *    • SCL3300 inclinometer → CAN (ID 0x7DE)
 *    • Robot state exchange (ID 0x6E0) — also reports this firmware's
 *      FW_VERSION in bytes 5-6; see the FIRMWARE IDENTITY block below and
 *      ros_ws/docs/platform_fw_version.md
 *    • TIME‑SYNC layer (ID 0x7DD)
 *      – Maintains wall‑time offset (Jetson wall‑time − micros64())
 *      – Prints jitter stats once per second
 *
 *  INVARIANT I-FW-15 (since FW 7, skill-stack R1).  The can-bridge is the SOLE
 *  axis-6 writer: this board neither transmits to CAN node 6 nor subscribes to
 *  its encoder.  This board's TX set is the inclinometer frame (0x7DE), the
 *  RobotState reply (0x6E0), the firmware-update reply (0x6F1) and the traffic
 *  report (0x7DF) — nothing else.  The stroke engine (Trajectory.h, the 0x6D0
 *  TRAJ_CMD decode, the 0x0C9 hand-encoder cache) was deleted with it.
 *
 *  NOTE on CAN IDs:
 *    ODrives occupy 0x000–0x0DF (7 × 32 IDs). Broadcast ID 0x7E0..0x7FF must
 *    also stay free.  All custom IDs here (0x6E0–0x7DF) are safe.
 *****************************************************************************************/

#include <Arduino.h>
#include <FlexCAN_T4.h>
#include <SPI.h>
#include <SCL3300.h>
#include "hardware_config.h"  // Auto-generated from config/hardware_config.yaml
#include "protocol_config.h"  // Auto-generated from config/protocol_config.yaml

#define DEBUG_TRAFFIC 0    // 0 = silent, 1 = Serial print report CAN traffic frames
#define DEBUG_TIME_SYNC 0  // 0 = silent, 1 = Serial print periodic messages showing how tight the clocks are synced

/*----------------------------------------------------------------------------*/
/*                        F I R M W A R E   I D E N T I T Y                   */
/*----------------------------------------------------------------------------*/
/*  Mirrors the can-bridge's identity block (Teensy_code_canbridge/
 *  canbridge_config.h, `CanBridge::FW_NAME` / `FW_VERSION`): a hand-authored
 *  marker with its bump history inline, printed at boot AND — unlike the
 *  can-bridge, which has a USB serial console the Jetson can read — reported to
 *  the host over CAN, because nothing on this board is reachable from the Jetson
 *  except through the can-bridge conduit.
 *
 *  WHY THIS EXISTS.  Until 2026-07-27 this board carried no version of any kind,
 *  so an UN-FLASHED Platform Teensy was indistinguishable from a flashed one from
 *  the Jetson: no log line, no field, no warning.  Every other deployment step in
 *  the stack fails loudly when skipped (a stale colcon install throws; a stale
 *  jugglebot_interfaces build kills trajectory_node ~200 ms after launch) — the
 *  firmware was the only one that failed SILENTLY, because a pre-fix board simply
 *  behaves like a pre-fix board.
 *
 *  WHERE IT IS REPORTED: bytes 5-6 of the 0x6E0 RobotState reply
 *  (`createStateCANMessage`), which were previously hard-zeroed reserved bytes.
 *  That choice is load-bearing, not incidental — see the frame-layout comment on
 *  `createStateCANMessage` for why the pre-versioning board's zeros ARE the
 *  sentinel.
 *
 *  VERSION SEMANTICS (identical to the can-bridge's): this is a human-facing
 *  identity marker.  It has NO runtime effect on this board and gates nothing;
 *  the host WARNS on a skew and never refuses a hand command
 *  (ros_ws/docs/platform_fw_version.md § Warn, never refuse).
 *
 *    0 = "pre-versioning" — no numbered release; the board predates this block.
 *        NEVER assign 0 to a release.  It is reserved as the sentinel a
 *        pre-2026-07-27 board transmits for free (its `createStateCANMessage`
 *        zero-fills bytes 5-7 unconditionally).
 *    1 = 2026-07-27.  First numbered release.  Carries the velocity-continuous
 *        `makeSmoothMove` (`Trajectory.h`, commit 5369fc2): the quintic is seeded
 *        from the live `current_hand_velocity` instead of v = 0, the empty-return
 *        branch is now conjunct on at_rest as well as |delta| < 1e-6, and the
 *        duration bound is the positive root of the corrected quadratic (capped by
 *        `smoothMoveMaxDuration()`).  Plan: plans/archived/hand-command-continuity.md
 *        Phase 4.  Also carries this identity block itself.
 *    2 = 2026-07-28.  POST-RELEASE DECELERATION FEEDFORWARD.  `Trajectory.h`'s
 *        `buildThrow` now sizes the torque feedforward of the decel segment
 *        (x2 -> x3, after the ball has left) from the axis's TOTAL reflected
 *        inertia — `throwDecelToTorque`, 9.5e-6 kg m^2 — instead of from
 *        `accelToTorque`'s hand-mass-on-a-spool model, which implied 7.3695e-6
 *        and so under-torqued the brake by ~30 %.  The commanded POSITION and
 *        VELOCITY streams are BIT-IDENTICAL to v1 on every kind; the accel and
 *        velocity-hold torques, all of kind 1, and `makeSmoothMove` are
 *        untouched.  Fixes the light end-stop contact measured at ~1.2 m throws
 *        on 2026-07-27.  Contract: C-HAND-2, retired with this code at FW 7;
 *        its surviving measurements are ros_ws/docs/hand_throw_envelope.md
 *        § Surviving measurements.  Plan: plans/archived/hand-command-continuity.md Phase 7.
 *        A v1 board is not unsafe, it simply still coasts — but every
 *        § CHECK HAND-7 row is meaningless on one, so read FW-1 first.
 *
 *  Bump on any behavioural change worth telling a bench operator about, and add a
 *  line above saying WHAT changed and WHEN (the can-bridge's comment style).
 *
 *    4 = 2026-09-08.  FW 18 BUNDLE hand-clip re-measurement — BEHAVIOURAL.
 *        Geometry::HAND_MOTOR_HARD_STOP_REVS 10.8 → 10.701 rev (operator
 *        re-measurement, config/hardware_config.yaml). Trajectory.h consumes it
 *        directly (no compensating margin widening this time, unlike 2→3):
 *        SMOOTH_MOVE_POS_CEIL_REV moves 10.60 → 10.501 rev, and
 *        smoothMoveMaxDuration() 0.78964 → 0.78602 s, tightening which branch
 *        makeSmoothMove takes for a prelude whose honoured duration lands in
 *        (0.78602, 0.78964] s, i.e. |v0| in (20.03, 20.14] rev/s. Conservative:
 *        that (now slightly wider) band takes the rest-to-rest fallback. This
 *        version bump is a HOST-side ripple of the can-bridge's FW 18 (which
 *        added `hand_clip_margin_rev` for its OWN, differently-shaped clip
 *        guard) — this board carries no clip-margin logic of its own; only the
 *        shared `hand_motor_hard_stop_revs` moved. Plan:
 *        plans/archived/unified-7dof-planner.md § FW 18 bundle. Logbook:
 *        logbook/2026-09-08-fw18-bundle-hand-clip-homing-counters-rename.md
 *    5 = 2026-09-09.  FIRST IMAGE THAT CAN BE UPDATED OVER CAN.  Adds the
 *        0x6F0/0x6F1 firmware-update endpoint (§ FIRMWARE UPDATE OVER CAN
 *        below): BEGIN/DATA/VERIFY/COMMIT, flash staging above the running
 *        image, CRC-32 + identity gate, then a FlasherX-style self-copy and
 *        reboot.  Motion behaviour is BIT-IDENTICAL to FW 4 — no trajectory,
 *        tilt, time-sync or RobotState path was touched — with one deliberate
 *        exception: while an update session is open this board REFUSES to arm
 *        new 0x6D0 trajectories (a sector flush stalls the streamer for tens
 *        of ms, which is not a thing to do mid-throw).
 *        ⚠ THIS IMAGE MUST BE FLASHED OVER USB ONCE, from the Arduino IDE.  A
 *        board running FW ≤ 4 has no 0x6F0 listener, so it cannot be given its
 *        own successor over CAN; FW 5 is the bootstrap that opens the path.
 *        Why the path exists at all: this board's micro-USB port is physically
 *        damaged and the Teensy bootloader chip speaks ONLY USB, so after this
 *        one flash, CAN is the only remaining route in.
 *    6 = 2026-09-09.  FIRST IMAGE BUILT ON THE JETSON (`pio run -e teensy40
 *        -t upload`) and flashed over CAN.  No code change beyond the number:
 *        with the USB console gone, the STATE_READ version (5 -> 6) is the
 *        only proof the copy landed and the new image runs.
 *    7 = 2026-09-11.  STROKE ENGINE DELETED — skill-stack R1, one hand master.
 *        Gone: `Trajectory.h` (makeThrow/makeCatch/makeFull/makeSmoothMove/
 *        throwDecelToTorque/accelToTorque), the 0x6D0 TRAJ_CMD decode and its
 *        smooth-move prelude, the packed-frame scheduler that streamed
 *        set_input_pos to CAN node 6, and the 0x0C9 hand-encoder cache.  After
 *        this image the can-bridge is the SOLE axis-6 writer (I-FW-15) and this
 *        board never transmits to node 6 at all.  UNCHANGED: the SCL3300
 *        inclinometer (0x7DE), the TimeSync slave (0x7DD), the RobotState
 *        exchange incl. the FW_VERSION reply bytes and the cold-start state,
 *        the traffic monitor, and the 0x6F0/0x6F1 firmware-update endpoint —
 *        whose BEGIN/COMMIT `engineIdle()` guard went with the streamer it
 *        protected (there is no longer a throw to reboot into the middle of;
 *        `ST_BUSY` is retired but its number stays reserved).  Plan:
 *        plans/active/two-ball-skill-stack.md § 4 R1.
 */
constexpr char     FW_NAME[]  = "jugglebot-platform";
constexpr uint16_t FW_VERSION = 7;   // 1→2: 2026-07-29 throwDecelToTorque (post-release decel
                                     //      feedforward, C-HAND-2).
                                     // 2→3: 2026-08-18 hand END-STOP correction — BEHAVIOURAL.
                                     //      Geometry::HAND_MOTOR_HARD_STOP_REVS 11.1 → 10.8 rev
                                     //      (operator-measured metal contact). Trajectory.h
                                     //      consumes it: SMOOTH_MOVE_POS_CEIL_REV is UNCHANGED at
                                     //      10.60 rev (the margin moved 0.5 → 0.2 to hold it), but
                                     //      smoothMoveMaxDuration() 0.80054 → 0.78964 s, which
                                     //      changes which branch makeSmoothMove takes for a
                                     //      prelude whose honoured duration lands in
                                     //      (0.78964, 0.80054] s, i.e. |v0| in (20.04, 20.32] rev/s.
                                     //      Conservative: that band now takes the rest-to-rest
                                     //      fallback. See logbook/2026-08-18-hand-end-stop-corrected.md
                                     // 3→4: 2026-09-08 FW 18 BUNDLE hand-clip re-measurement —
                                     //      BEHAVIOURAL. HAND_MOTOR_HARD_STOP_REVS 10.8 → 10.701
                                     //      rev; SMOOTH_MOVE_POS_CEIL_REV 10.60 → 10.501 rev;
                                     //      smoothMoveMaxDuration() 0.78964 → 0.78602 s. See the
                                     //      identity-block entry above for the full derivation.
                                     // 4→5: 2026-09-09 FIRMWARE UPDATE OVER CAN (0x6F0/0x6F1).
                                     //      Motion paths bit-identical to FW 4; the only
                                     //      behavioural change outside the new endpoint is that
                                     //      0x6D0 trajectory arming is refused while an update
                                     //      session is open. FW 5 must be USB-flashed once — a
                                     //      FW ≤ 4 board cannot receive its own successor.
                                     // 5→6: 2026-09-09 the first image BUILT ON THE JETSON
                                     //      (`pio run -e teensy40 -t upload`) and flashed over
                                     //      CAN. No code change beyond this number: the bump IS
                                     //      the receipt — with the USB console gone, the
                                     //      STATE_READ version (5 → 6) is the only proof the
                                     //      copy landed and the new image runs.
                                     // 6→7: 2026-09-11 skill-stack R1 — stroke engine deleted:
                                     //      0x6D0 decode, hand encoder cache, Trajectory.h.
                                     //      Inclinometer / time-sync / RobotState / firmware
                                     //      update unchanged. The can-bridge is now the sole
                                     //      axis-6 writer (I-FW-15).

/*----------------------------------------------------------------------------*/
/*                                CAN BUS SET‑UP                              */
/*----------------------------------------------------------------------------*/
FlexCAN_T4<CAN1, RX_SIZE_256, TX_SIZE_16> can1;
constexpr uint32_t CAN_BITRATE = CanBus::BAUD_RATE;

/*----------------------------------------------------------------------------*/
/*                             INCLINOMETER (SCL3300)                         */
/*----------------------------------------------------------------------------*/
SCL3300 inclinometer;

/*----------------------------------------------------------------------------*/
/*                               CAN  ID MAP                                  */
/*----------------------------------------------------------------------------*/
// CAN IDs from protocol_config.h
constexpr uint32_t REPORT_ID      = PlatformCanId::TRAFFIC_REPORT;
constexpr uint32_t tiltID          = PlatformCanId::TILT_READING;
constexpr uint32_t timeSyncID      = SharedCanId::TIME_SYNC;
constexpr uint32_t stateUpdateID   = PlatformCanId::STATE_UPDATE;
constexpr uint32_t FW_UPD_CMD_ID   = PlatformCanId::FW_UPDATE_CMD;    // host → this board
constexpr uint32_t FW_UPD_REPLY_ID = PlatformCanId::FW_UPDATE_REPLY;  // this board → host

/*----------------------------------------------------------------------------*/
/*                            TRAFFIC MONITOR                                 */
/*----------------------------------------------------------------------------*/
uint32_t receivedCount = 0;
uint32_t lastReportTime = 0;
constexpr uint32_t reportInterval = TeensyOp::REPORT_INTERVAL_MS;

/*----------------------------------------------------------------------------*/
/*                      DEBUG / TIMING‑ANALYSIS                               */
/*----------------------------------------------------------------------------*/
const uint32_t node_id = 0;
const uint32_t cmd_id = 0x018;
const uint32_t debugID = (node_id << 5) | cmd_id;

uint32_t timingID = (node_id << 5) | 0x04;
uint16_t targetContentID = 385;
unsigned long lastMessageTime = 0;
const unsigned long analysisPeriod = 500;
unsigned long totalIntervals = 0;
int messageCount = 0;

/*----------------------------------------------------------------------------*/
/*                             ROBOT STATE                                    */
/*----------------------------------------------------------------------------*/
struct RobotState {
  bool is_homed;
  bool levelling_complete;
  float pose_offset_tiltX;
  float pose_offset_tiltY;
};
RobotState state = { false, false, 0.0f, 0.0f };

/*----------------------------------------------------------------------------*/
/*                           PLATFORM TILT                                    */
/*----------------------------------------------------------------------------*/
struct platformTilt {
  float tiltX;
  float tiltY;
};

/*----------------------------------------------------------------------------*/
/*                        ──  TIME–SYNC  LAYER ──                             */
/*----------------------------------------------------------------------------*/
namespace TimeSync {

/* 64‑bit free‑running microsecond counter (wraps after 71 min) */
/* ISR-SAFE: wrap detection runs with interrupts masked (same idiom as
 * BallButler ball_butler_main/Micros64.h). The unguarded version is racy
 * whenever an ISR and the main loop both call it — an in-call preemption that
 * advances last_lo reads as a false 32-bit wrap (+2^32 µs on the clock). That
 * bit the catching cone (piezo ISR) on 2026-06-10; this copy had no ISR
 * caller but is fixed for parity per the keep-in-sync rule — see
 * logbook/2026-06-10-cone-micros64-false-wrap.md. NOT yet flashed to the
 * platform Teensy (deploy on its next natural firmware update). */
uint64_t micros64() {
  uint32_t primask;
  asm volatile("MRS %0, PRIMASK" : "=r"(primask) :: "memory");
  __disable_irq();

  static uint32_t last_lo = 0;
  static uint64_t hi = 0;
  uint32_t now = ::micros();
  if (now < last_lo) hi += UINT64_C(1) << 32;
  last_lo = now;
  uint64_t result = hi | now;

  if ((primask & 1u) == 0u) __enable_irq();  // re-enable only if enabled before
  return result;
}

/* Wall‑time offset: Jetson_wall_us − micros64() */
volatile int64_t wall_offset_us = 0;
volatile bool have_offset = false;
constexpr uint8_t ALPHA_SHIFT = TeensyOp::TIME_SYNC_ALPHA_SHIFT;  // I‑filter gain = 1/2^n

/* Stats for jitter read‑out */
struct Stats {
  int32_t sum = 0;
  uint32_t sum_sq = 0;
  int32_t min = INT32_MAX, max = INT32_MIN;
  uint32_t n = 0;
  void add(int32_t x) {
    sum += x;
    sum_sq += uint32_t(x) * x;
    if (x < min) min = x;
    if (x > max) max = x;
    ++n;
  }
  void clear() {
    *this = {};
  }
  float mean() const {
    return n ? float(sum) / n : 0.f;
  }
  float rms() const {
    return n ? sqrtf(float(sum_sq) / n) : 0.f;
  }
} stats;
uint64_t nextPrint_us = 0;
constexpr uint32_t PRINT_PERIOD_US = 1'000'000;

/* Convert helpers (can be used by main application) */
uint64_t get_wall_time_us() {
  return micros64() + wall_offset_us;
}
uint64_t wall_to_local_us(uint64_t w_us) {
  return w_us - wall_offset_us;
}

/* Process a single 8‑byte sync frame (ID 0x7DD) */
inline void handleSyncFrame(const CAN_message_t &msg) {
  uint32_t sec = msg.buf[0] | (msg.buf[1] << 8) | (msg.buf[2] << 16) | (msg.buf[3] << 24);
  uint32_t usec = msg.buf[4] | (msg.buf[5] << 8) | (msg.buf[6] << 16) | (msg.buf[7] << 24);
  uint64_t jetson_us = uint64_t(sec) * 1'000'000ULL + usec;
  uint64_t local_us = micros64();
  int64_t offset = int64_t(jetson_us) - int64_t(local_us);

  if (!have_offset) {  // first frame → step
    wall_offset_us = offset;
    have_offset = true;
  } else {  // subsequent → slew
    int64_t diff = offset - wall_offset_us;
    wall_offset_us += diff >> ALPHA_SHIFT;
  }

  /* delta from current offset for jitter stats */
  int32_t delta = int32_t(offset - wall_offset_us);
  stats.add(delta);
}

/* Periodic console print */
inline void maybePrintStats() {
  uint64_t now = micros64();
  if (now < nextPrint_us) return;
  nextPrint_us = now + PRINT_PERIOD_US;

  if (stats.n) {
    Serial.printf("Δmean %+0.1f us | rms %.1f us | min %+d us | max %+d us | frames %lu\n",
                  (double)stats.mean(), (double)stats.rms(),
                  stats.min, stats.max, stats.n);
    stats.clear();
  }
}
}  // namespace TimeSync
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
void loop() {
  can1.events();   // dispatch CAN callbacks
  reportStatus();  // traffic monitor
  FwUpdate::tick();  // time out an abandoned firmware-update session

  #if DEBUG_TIME_SYNC
    TimeSync::maybePrintStats();  // console jitter read‑out, if desired.
  #endif
}

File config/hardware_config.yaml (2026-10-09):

# ===========================================================================
# hardware_config.yaml — Centralised hardware & geometry constants
#
# Single source of truth for all hardware dimensions, physical properties,
# tuning parameters, and operational constants across the Jugglebot system.
# CAN protocol constants live separately in jugglebot_protocol.yaml.
#
# Consumed by: generate_config.py → hardware_config.py (Python)
#                                  → hardware_config.h  (C++)
#
# To regenerate: python config/generate_config.py
#
# Section grouping:
#   1       Shared Physics
#   2–3     Jugglebot (Stewart platform geometry, homing)
#   4       ODrive Expected Versions
#   5–7     Jugglebot (ODrive defaults, operational, SpaceMouse)
#   8–9     Teensy (platform microcontroller)
#   10      Motion Capture
#   11      Ball Tracking & Prediction
#   12–22   Ball Butler
# ===========================================================================

# ============================================================
# 1. Shared Physics
# ============================================================
physics:
  gravity_mps2: 9.806       # Gravitational acceleration (m/s^2). Used by both Teensys (trajectory planning)
                             # and Python (ball tracking/prediction). NOTE: Some legacy Python files use 9.81 — this
                             # value (9.806) matches the firmware and is the canonical value going forward.

  # ---- Juggling ball ----
  # Owner-stated 2026-08-21: 71 g, 70 mm diameter.  Canonical source for the
  # MuJoCo ball geom, which `sim/model/generate_mjcf.py` reads directly from this
  # file; before 2026-08-21 the number was hardcoded in TWO places that disagreed
  # (jugglebot.xml 0.035/0.071, the generator 0.02/0.043).
  #
  # ⚠ NOT the same quantity as `throw_envelope.BALL_MASS_KG` (0.0952 kg), which is
  # the ball mass IMPLIED by `INERTIA_RATIO = m_hand/(m_hand + m_ball)` = 0.747.
  # Those two disagree by +34 %: 0.747 back-solves to a 95.2 g ball, the physical
  # ball is 71 g (which would give INERTIA_RATIO 0.798).  The disagreement is
  # UNRESOLVED and deliberately not reconciled here — INERTIA_RATIO is a tuned,
  # hardware-validated throw-shaping constant baked into firmware, not a
  # measurement of the ball.  The names are kept distinct on purpose so that
  # `hw.JUGGLING_BALL_MASS_KG` can never be mistaken for the envelope's value.
  juggling_ball_mass_kg: 0.071      # Physical mass of one juggling ball {kg}.
  juggling_ball_radius_mm: 37.0     # Physical radius of one juggling ball {mm}
                                    # (74 mm diameter / 2, owner caliper measurement 2026-08-21).
                                    # Was 35.0 (an assumed "70 mm ball") until then — the 35 mm that
                                    # appears elsewhere in this repo as a CAPTURE RADIUS is a
                                    # different quantity and is NOT superseded by this.
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

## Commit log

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2026-07-29 fix(canbridge): CAN3 command gate keys on SUSTAINED error-passive + CanErrors uplink
    Root cause (investigation in the logbook entry): the hand-sensor poller's
    50 Hz RxSdo transaction drives CAN3 into error-passive (TEC/REC >= 128;
    ~16 failed transmissions per burst), and jugglebot_commands_allowed()'s
    instantaneous WARN refusal turns that into a measured self-sustaining
    limit cycle - 42.4% WARN duty, 426 transitions in 83.5 s, with only
    28.94% of poll slots served, in a session where six identical pre-flash
    idle controls show 0.0%. Refusing TX also removes the decay pump that
    heals TEC, and one shared predicate amplifies a low-rate error source
    into a system-wide command outage. Zero BUS_OFF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
    [Teensy_code_canbridge.ino]
2026-07-31 firmware(canbridge): TEMP default the hand-sensor poller OFF at boot (CAN3 fault isolation)
    CAN3 wire errors persist after the operator's thorough physical-layer
    inspection (no visible damage; CANH/CANL 66 ohm powered-off, i.e. both
    terminators present). To decide whether the hand-sensor poll traffic is
    a necessary condition for the errors, the poller's RUNTIME boot default
    flips to OFF (s_enabled=false in gpio_poll_init) so every boot starts
    radio-silent; serial gpio_poll on|off still toggles it live, enabling
    the strong version of the experiment (flip while errors are actively
    ticking, watch the CanErrors counters respond).
    Deliberately NOT the YAML kill switch (jugglebot_ball_detect.enab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
    [Teensy_code_canbridge.ino, gpio_poll.cpp]
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2026-07-31 fix(canbridge): CAN3 drive-path fault - Jugglebot moves to the CAN2 controller; cone health on the uplink; FW7
    Root cause of the 2026-07-29 CAN3 instability (logbook entry in this
    commit): the bridge's CAN3 analog drive path fails under load - clean at
    a sustained 100 Hz into the 1-node cone bus, dead within seconds against
    the 8-node Jugglebot chain (bit1-dominant TX-context corruption,
    error-passive to BUS_OFF, FlexCAN infinite retransmit = "once started,
    never stops"). Software exonerated by exhaustion: poller silenced (v6),
    USB unplugged, bridge FW3 rollback, Platform Teensy V1 rollback (Arduino
    IDE toolchain, keeping the code delta unconfounded), a different hand
    ODrive, the Platform Te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
    [Teensy_code_canbridge.ino, gpio_poll.cpp]
2026-07-31 feat(protocol+platform): cone PROFILE slot (UDP v5, FW8) + Teensy_code_platform rename + buttonless platform flashing
    Three follow-ups closing the CAN3 saga's loose ends:
    1. Cone PROFILE slot: Profile gains can3_rx/can3_tx/can3_util_x100
    (appended at the end so every pre-existing field keeps its offset;
    payload 66 -> 76 B). PROTOCOL_VERSION 4 -> 5 (incompatible layout
    change on an existing frame - Jetson checkout and flashed bridge must
    match), FW_VERSION 7 -> 8. profiling.cpp fills slot 3 from the cone
    role's counters; the node publishes can3_* KeyValues on /profile; the
    GUI cone row gets full traffic charts (slot 'can3') and drops the
    3rd-slot TODO tooltip. Wire diges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
    [hardware_config.yaml]
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2026-08-02 feat(canbridge): BRIDGE_TX_DIAG + BRIDGE_IDENTITY additive uplinks (FW9)
    Two additive MsgTypes close the attribution gap the 2026-08-01 ERR_TIMEOUT
    recount hit: it could establish THAT the hand arm-ack fails about half the
    time, but not which of hand_ops' three CAN sends refused, nor whether a
    refusal meant a lost frame.
    BridgeTxDiag (0x8D, 42 B) carries per-bus tx_deferred + tx_q_hwm and the
    per-stage hand tally. The counter is named tx_deferred, not tx_write_fail,
    because the name outlives the investigation: FlexCAN_T4::write() on this
    overload returns 1 or -1 and never 0, and -1 means the frame was pushed into
    the 64-slot software txBuffer that the TX-complete ISR drains. A refused send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
    [Teensy_code_canbridge.ino]
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2026-08-09 fix(canbridge): 16 TX mailboxes on the jugglebot bus + hand-dispatch phase stamp (FW10)
    The measured mechanism (bench 2026-08-09, FW 9): with setMaxMB(16) the Jugglebot
    bus had EIGHT TX mailboxes, and the 500 Hz interp ISR fills six of them in one
    back-to-back burst. A hand dispatch landing in the post-burst window found no free
    mailbox, FlexCAN_T4::write() returned -1 (deferral into the software ring), and
    hand_ops reported ERR_TIMEOUT. Three-arm A-B-A ladder, N=40/arm: idle 0/40,
    500 Hz leg stream 15/40, idle again 0/40 at higher uptime (Fisher p = 8.5e-09),
    can3_errors zero throughout. The per-stage split pre1 0 / pre2 7 / traj 8 reads
    out the pending-mailbox count directly.
    setMaxMB(16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
    [Teensy_code_canbridge.ino]
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2026-08-10 feat(config): toss tier 8a as shipped default + settle/catch-vel tunings; 8b tests pin the tier
    Owner decisions 2026-08-10 after the tilt-map validation and 8a toss retest:
    - toss_tier: 8b -> 8a (supersedes the 2026-07-28 8b default; the 8b
    capability stays in code and its tests now pin the tier explicitly as a
    capability under test rather than inheriting the shipped default)
    - levelling_settle_s: 0.5 -> 1.0 and catch_vel_scale_default: 0.8 -> 0.9
    (operator-tuned during the 8a vertical-toss retest; most throws caught)
    - generated artifacts regenerated, drift gate CONFIG FRESH 14/14
    Test repairs the flip exposed:
    - 12 toss tests pinned 8b implicitly (chain-site policy, displacement cap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
    [hardware_config.yaml]
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2026-08-10 feat(toss): ball-evidence gate ON by default, read LIVE from the hand sensor
    The 2026-07-25 default false was justified by one stated condition - "there is NO
    ball-in-cup sensor", so a throw could only be gated on an unreliable
    tracker-derived belief and a physically-loaded ball would be refused. That
    condition no longer holds. The operator validated the sensor in situ on
    2026-08-10 and authorised the flip, which SUPERSEDES the hand-ball-sensor plan's
    "forbidden until Phase 7 validates" gate (recorded at that plan's own statement
    of it; Phase 7 steps 4-5 stay open as bench tuning, not blockers).
    C-POSSESS-1 3.3, i.e. both coordinator edits 7.1 named as outstanding:
    1. CHECKING is a LIVE so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
    [hardware_config.yaml]
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2026-08-10 feat(toss): the auto-reload interlude - one quiescent entry, a named refusal per rung
    TossContinuous gains on_empty_cup (IDL default STOP, re-applied by a WHITELIST -
    anything not exactly RELOAD is STOP, because the failure being prevented is a real
    ball thrown by a field nobody meant to set) and max_reloads (0 => config 3,
    negative refused BY NAME), plus one motion-bearing interlude entered from
    REJECTED_NO_BALL ONLY: the single toss terminal where the FSM provably commanded
    nothing, so the machine is quiescent when it starts.
    Every rung is an existing validated mechanism - trajectory/go_home, then the
    shipping ReloadSequencer driven through the node's own _step_sequence - so the
    interlude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
    [hardware_config.yaml]
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2026-08-12 feat(bridge-temporal S2): FW 12 CACHE_DIAG - per-axis cache-age census + the split S1 could not make - written, compiled, NOT flashed
    Additive MsgType 0x91 (129 B, PROTOCOL_VERSION stays 5, first id of the new
    block above RPC_RESPONSE): per-axis encoder-cache age min/max per 1 Hz window
    (task-side samples through the existing seqlock - zero ISR work, no IRQ
    masking), per-axis enc_frames counters incremented AFTER write_pos_vel
    (advanced => cache write completed: splits ODrive-went-silent from
    cache-stopped-updating, the one distinction the S1 bags could not make), the
    2026-06-04 drain-fix's never-uplinked depth_hwm/cap_hits, and decode-discard
    counters. /cache_diag bagged; FW_VERSION 11->12;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
    [Teensy_code_canbridge.ino]
2026-08-12 fix(canbridge): MOTOR_FB_STALE guard - atomic timestamp read + now>ts ordering guard
    The feedback-staleness guard read pos_timestamp_us with a naked u64 load (two
    32-bit reads, tearable by the higher-priority CAN-RX writer) and no ordering
    guard against a stamp landing after the loop's now capture (unsigned wrap past
    the threshold = a false one-tick MOTOR_FB_STALE, ~100 ms output suppression
    mid-motion; the torn read could also mask a real freeze for a tick). Both
    halves closed; the heartbeat guards share the ordering half and are a flagged
    follow-up. Ships in the FW 12 image.
    Logbook-Entry: 2026-08-12-fault-machine-staleness-guard-atomic-read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
    [fault_machine.cpp]
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2026-08-12 fix(config): leg snapshot - hall_encoder1 back to the original backup, trap_traj kept
    The leg-ODrive snapshot was re-captured from a live drive this session, which
    brought three unintended changes along with the intended ones. Owner adjudicated:
    - trap_traj vel/accel/decel limits (20.0 -> 2.5, 10 -> 30, 8 -> 30): INTENDED,
    kept.
    - hall_encoder1: the capture had it enabled with calibrated edges and
    hall_polarity 192, where the original backup has it disabled. NOT intended -
    all 9 properties restored programmatically from HEAD rather than hand-typed,
    so no transcribed float lands in a file that gets flashed to six drives.
    - axis0.controller.config.vel_limit 4.0 -> 12.0: left as captur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
    [odrive_pro_leg_config.json]
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2026-08-14 feat(bridge-temporal S3): FW 13 RING_DIAG - the ring-leak conviction instrument + the /robot_state honesty gate
    Additive MsgType 0x92 (103 B, PROTOCOL_VERSION 5): per-bus TRUE ring occupancy
    probed immediately after the drain loop, where _available is zero by definition
    - true_depth IS the stranded leak, and true_depth - avail_reported is the
    conviction number; leak/depth high-water per 1 kHz service tick; FIFO
    overflow/warning counters (never counted before); a wrap-aware delivery-lag
    integral with decode-gap AND physical-cap (200 ms > one ring lap) reseeds; and
    an SDO round-trip floor wrapping the existing 50 Hz hand-sensor poll as the
    causal cross-check. Two minimal marked patches on the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
    [Teensy_code_canbridge.ino, gpio_poll.cpp]
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2026-08-16 docs+test: three-way plans board, never-rename-on-archival, and levelling ownership resolved
    Two documentation change-sets that landed together and share files.
    PLANS BOARD. plans/ is now active/ (schedulable now), parked/ (deliberately
    not now) and archived/ (done or superseded), each with its own INDEX. Six
    plans moved to parked/, and every parked row names WHAT WOULD UNPARK IT - the
    column that makes the board answer "what next" instead of just listing what is
    dormant. One plan states no gate at all, and the row says so plainly rather
    than inventing a blocker.
    Archival stops renaming. The date prefix was the single thing breaking every
    inbound reference: related_plan is filename-only by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
    [hardware_config.yaml]
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2026-08-18 fix(hand): remove the asymmetric -10.00 A torque clamp; close catch-robustness 0/1
    The hand ODrive's axis0.config.torque_soft_min was -0.055133331567049026 N.m,
    which at the hand's Kt of 0.0055133 is exactly -10.00 A, asymmetric against a
    torque_soft_max of +0.5 N.m. It truncated the FW-2 post-throw decel feedforward
    on every throw above ~0.38 m and produced the dip seen on 54/54 measured throws.
    The operator's bench ladder confirmed H7.0c's pre-registered hypothesis and set
    both clamps to a symmetric +/-0.7 N.m, with save_configuration() run; the
    committed snapshot now matches. Both sit far outside current_soft_max = 50.0 A,
    so the current limit is the fence on both sides.
    Likely origin: -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
    [odrive_pro_hand_config.json]
2026-08-18 fix(hand)!: end stop is 10.8 rev, not 11.1 - the shipped guard sat past metal
    The hand's physical hard stop is 10.8 rev (metal contact), measured by the
    operator on the sensorised hand - the hand changed during ball-sensor
    integration and the limit was never updated. Every declared value was too high,
    one-sidedly: the shipped guard 11.1 (0.3 rev / 9.5 mm PAST metal), its own
    comment's "true max ~11.4", geometry's 11.224 from hand_stroke_mm 355, and
    runbook H4.5's 11.124.
    So clip_position - in the host and in the can-bridge firmware - would accept and
    pass a commanded setpoint 9.5 mm into the stop. It also mis-scored history: the
    2026-07-27 sitting's five ~1.2 m tosses at 10.8601-11.0621 rev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
    [hardware_config.yaml]
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2026-08-20 feat(toss)!: derive the throw envelope from machine limits; fix both HAND criteria
    TWO changes that turned out to depend on each other.
    1. THROW ENVELOPE (contract C-HAND-3, ros_ws/docs/hand_throw_envelope.md)
    FLIGHT_TIME_MIN_S = 0.55 and FLIGHT_TIME_MAX_S = 1.10 were hand-picked. They are
    replaced by a derived envelope at one enforcement point (throw_envelope.evaluate),
    seven bounds, every input a config key, refusals naming the binding bound with
    numbers. Owner directive: the machine's limits should come from its configured
    accel/velocity/torque/timing limits, not from constants.
    Two passes, and the second overturned the first. The first had only the
    2026-07-27 PRE-CLAMP-FIX coast ladde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
    [hardware_config.yaml]
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2026-08-21 chore(plans): remediate and archive hand-command-continuity
    A plan-reviewer blocked archival with a list that was bookkeeping, not
    engineering - every phase is implemented, flashed (Platform FW 3, can-bridge
    FW 15) and hardware-validated to the throw envelope's ceiling. Two items would
    have cost a powered sitting.
    THE TWO EXPENSIVE ONES
    session_anomaly_fixes.md rows FW-1 and H4.0d gave PASS as "Platform Teensy
    reports v2" and routed anything else to "git pull + re-flash". The board and
    PLATFORM_FW_VERSION_EXPECTED are both on 3, so the runbook scored a correctly
    flashed board as a FAIL. And C-HAND-1 obligation F still read "NOT LIVE until
    the Platform Teensy is flashed" - the same stalenes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
    [hardware_config.yaml]
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2026-08-21 feat(sim)+test: the MJCF model is a generated artifact again, and stays one
    sim/model/jugglebot.xml stopped being generated on 2026-03-30 and nobody noticed
    for five months. The histories diverge at 1953943; the generator's only later
    commits were comment/dead-code with no output change, while the XML took four
    substantive hand-edit commits. Running generate_mjcf.py today produced a 38-line
    diff of which ONE line was a wanted fix and the rest was destruction: it would
    have deleted the second ball outright (body, freejoint, geom, site, material,
    two sensors and the ball-ball exclude) and cut the ball from 35 mm / 71 g to
    20 mm / 43 g.
    Four general properties had to hold at once for that to s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
    [hardware_config.yaml]
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2026-08-21 feat(mocap): QTM-gated BB calibration with fail-closed refusals + hardening
    F4 of plans/active/operator-observability.md, Q1-Q6 (implementation spanned a
    salvaged agent hand-off after a mid-run spend-limit death):
    - Q1 mocap/status DiagnosticStatus at 5 Hz (qtm_receiving, bb_markers_visible,
    marker3_visible, aligned, qtm_synced) - first ROS-observable QTM liveness
    - Q2 bb/calibrate refuses fail-closed (QTM_STALE / BB_MARKERS_NOT_VISIBLE)
    before any RPC dispatch; BB-absent silent-skip branch stays first and pinned
    - Q3 HOMING skips-not-faults when QTM is not delivering BB markers
    - Q4 GUI Calibrate button disabled while mocap is disconnected, reason in tooltip
    - Q5 hardening: MIN_ARC_DEG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
    [bb_calibration.py]
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2026-08-21 fix(audit): Phase A closure - the arc-span floor gated the wrong signal, plus five
    Six approved findings from the independent Phase-A audit (F3+F4), all applied:
    1. BLOCKING: MIN_ARC_DEG measured span around the ill-conditioned circle-fit
    centre, so QTM-realistic noise (0.1-1.5 mm) made a 5 deg truncated sweep
    read 56-342 deg and the floor never fired on hardware; the per-marker
    exclusion inverted (noisiest stub kept, poisoning the axis average).
    Primary gate moved to the encoder-derived BB yaw series (angular_span_deg,
    branch-cut safe); MIN_MARKER_RADIUS_MM 20.0 catches the collapse signature;
    fixtures parametrised over noise_mm {0.0, 0.1, 0.5}.
    2. _guard_fault_leg_hint ma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
    [bb_calibration.py]
2026-08-21 fix(config)!: the ball is 74 mm across, not 70 - and the pin guarded 70
    Owner caliper re-measurement, 2026-08-21. physics.juggling_ball_radius_mm was
    35.0 carrying the comment "70 mm diameter / 2"; that was an assumed figure the
    repo had been repeating, and the ball measures 74 mm across. Mass (0.071 kg) was
    always measured and is unchanged.
    Three other sites carried the stale number:
    * sim/model/generate_mjcf.py's comment (the value itself already came from the
    YAML, which is why regenerating was enough);
    * tests/sim/test_mjcf_drift.py, whose pin asserted size="0.035" -- it was
    GUARDING THE WRONG VALUE, which is the failure a drift test is least able to
    notice about itself, since bo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
    [hardware_config.yaml]
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2026-08-21 fix(possession)!: the sensor windows stop outlasting the machine's own cadence
    The cadence census orders D1/D2/D3/D4/D6/D7 + F3 to land BEFORE rung R3, and
    names the alternative as "the single most dangerous change". This is that block,
    landed as ONE contract change rather than seven patches, because every item is an
    instance of the same root cause.
    Every sensor window in C-POSSESS-1 was justified by an inequality between the
    window and the machine's own dwell floor -- the catch band sits 4x clear of the
    next non-catch rise, retention closes 2.3x before the earliest legitimate
    departure. Retire the floor and those arguments do not degrade, they INVERT: a
    window that was 2.3x clear of the ne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
    [hardware_config.yaml]
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2026-08-24 feat(canbridge): the poller reaches its configured 50 Hz and a deferred TX stops reading as failure
    Folded into the UNFLASHED FW 15 with the hand end-stop change (owner decision
    2026-08-24): one combined upload later. The live bridge stays on FW 14 and the
    advisory expected-version skew alarm is unchanged - both constants were
    already 15 (bump-at-commit precedent, 3760daa). NOTHING FLASHED HERE.
    Poller: the one-in-flight state machine kept, but the AWAIT branch now falls
    through to consume-and-send in the same tick, and pacing runs on an absolute
    schedule with a half-tick early-fire band (an absolute schedule alone leaves
    the due grid ON the tick grid, so the wake-jitter coin flip survives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
    [Teensy_code_canbridge.ino, fault_machine.cpp, gpio_poll.cpp]
2026-08-24 feat(possession)!: the arrival band follows the healthy plant down
    Ladder section 3.1 resolved offline: the empty->held RAW edge's offset from
    the announced landing, re-measured on the post-FW-14 plant (33 pooled CAUGHT
    rows across 4 bags, eligibility by mined bridge_fw_version), reads
    +87.6 / +183.9 / +554.7 ms (min/median/max) against the shipped
    +137 / +399 / +798. ARRIVAL_BAND_MIN_S 0.137 -> 0.087 and ARRIVAL_BAND_MAX_S
    0.80 -> 0.56, sized by the originals' own policy: the datum floored to the ms
    (a true lower bound) and ceiled to the next 10 ms (+5.3 ms of pad). Too small
    mints MISSED on a real catch; padding past the datum destroys auditability.
    What the ceiling buys: CATCH_CONFIRM_WI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
    [hardware_config.yaml]
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2026-08-24 fix(canbridge)!: the poller + tri-state image becomes FW 16 - one number, one build
    The 2995855 fold into FW 15 rested on a false premise: the end-stop FW 15
    image has been ABOARD since ~2026-08-20 (the board self-reports 15 on
    BRIDGE_IDENTITY in every bag since; the 2026-08-18 entry recorded both
    flashes aboard on 2026-08-21). 2995855's message says "the live bridge
    stays on FW 14" - wrong, corrected in the logbook entry since a pushed
    message cannot be amended. Folding two behavioural images behind one
    number would have made bridge_fw_version blind to whether the poller +
    tri-state half is aboard - the exact failure the version check exists
    for. Owner re-decision 2026-08-24: FW_VERSION and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
    [Teensy_code_canbridge.ino, gpio_poll.cpp]
2026-08-25 close-out: the observability quartet archives - the headline names the fault, the gaps column stops lying, the floors split
    Close-out round of plans/archived/operator-observability.md (archived
    completed 2026-08-25 after the first bench sitting validated all four
    features on b705a21). Driven by the owner's bench feedback, the archival
    review, and a 15-finding audit of this diff - all findings applied.
    - GUI event log: "ODRIVE ERROR: <axis> <NAME>" headline (active-first,
    sticky-disarm fallback, ellipsis only when more names hide behind the
    first); hover decode unchanged; format tripwired.
    - Vendored ODrive-decoder class closed: free_platform, supported_platform
    and single_leg harnesse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
    [bb_calibration.py]
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2026-08-27 feat(toss): Phase B4 - the two-slot pipeline lands dormant, and the commit tick becomes the arm point
    The chained session gains a staged slot: CHECKING(static) -> POSITIONING
    (skip-only) -> PREPARING -> STAGED -> COMMITTING, run inside the
    previous cycle's flight. Exactly one tick stays on the critical path -
    the COMMIT, which re-reads the evidence set (link gates abort,
    hand_parked and ball_seated SLIP, track_active rejects, the runtime
    guard) and, in the same tick and in this order, publishes the
    announcement and dispatches the throw. ball_seated is read on the
    dispatch tick and nowhere earlier - the empty-stroke gate gets STRICTER
    under the pipeline, pinned structurally (T-U4) and as a te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
    [hardware_config.yaml]
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2026-08-28 fix(toss)!: first contact with the pipeline - one late tick was one deadlock, and a late commit now slips
    Bag 2026-08-28_10-31-35 (the first pipelined sitting) convicted the
    operator's three anomalies as ONE mechanism. The commit gate's runtime
    guard sat exactly one nominal loop period past the commit crossing,
    velocity-independent, on a Jetson whose non-RT time.sleep overshoots by
    up to ~13 ms - so a late iteration landing on the crossing fired
    ABORTED_CANT_MAKE_RELEASE (4/15 staged slots; the "structurally
    unreachable" claim refuted by first hardware contact). On the CAUGHT
    path the abandonment's only clearer had ALWAYS already run, so
    _stage_declined deadlocked the session in DWELL foreve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
    [hardware_config.yaml]
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2026-09-01 feat(toss): the robot plans itself whole - GI-QP cup cycles, banked realize, a 7-channel plan, hand gates, and the sim gate passes
    Phase 1 of unified-7dof-planner, pure software behind ships-false flags:
    - cup_cycle.py: Goldfarb-Idnani dual-active-set QP port of the sim
    planner (parity 1.9e-4 mm vs committed CasADi fixtures), event-timeline
    plan_window API, catch-runway hard constraint, cfg-gated cup accel
    boxes, feasibility-residual verification (a knife-edge cycle that
    converged 121 units off the manifold now refuses), early-catch
    rank-deficiency refused by name (CATCH_TOO_EARLY).
    - cup_realize.py + cycle_plan.py: apparent-gravity banking with an
    accel-bounded convexity-preserv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
    [hardware_config.yaml]
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2026-09-05 feat(toss): Phase 5 PREPPED, not flown - the unified-cycle key flips true (the per-goal field is now the ships-false element), a request-only bench driver for the carry and throw-only rungs, and a pl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
    Owner decisions 2026-09-05: guard ARMED from UH-3 on (a trip is data);
    full prep including the reviewed config flip; the runbook written as a
    recipe for the operator.
    - config/hardware_config.yaml: jugglebot_operational.unified_cycle_enabled
    false -> true (+ the one-line regenerated artifacts). Safe: every legacy
    goal stays legacy because TossContinuous.unified_cycle still defaults false;
    rollback is that field (or the constant).
    - tests/hardware/unified_cycle_b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
    [hardware_config.yaml]
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
